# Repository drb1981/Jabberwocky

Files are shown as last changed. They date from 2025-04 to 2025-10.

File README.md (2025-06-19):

# Jabberwocky

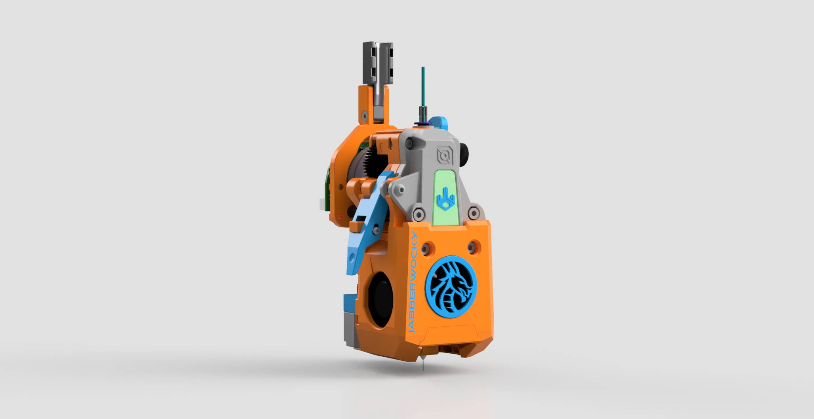
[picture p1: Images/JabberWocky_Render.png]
Jabberwocky Render


**JABBERWOCKY** has been engineered to meet the demanding requirements of filament changing units (FCUs) and multicolor changers. Its extruder is purpose-built to handle the rigorous load and unloading cycles of FCUs, utilizing a Bondtech compound drive gear in an offset configuration, paired with dual LDO non-threaded Orbiter gears for precise and reliable filament control.

The system offers a carefully optimized balance of torque and speed, along with increased surface contact on the filament to ensure stability and consistent feeding throughout operation.

Designed for maximum reliability and serviceability, the toolhead features a tool-free, hinged extruder mechanism, enabling fast and hassle-free maintenance.

Efficient thermal performance is delivered by high-static-pressure fans, ensuring airflow reaches critical areas, while the Phaetus Conch high-flow hotend enables smooth, consistent extrusion at volumes of up to 35 mm³/s.

For complete assembly instructions and additional technical details, please refer to our [Wiki](https://github.com/kinematicdigit/Jabberwocky/wiki).

Kits will be available through LDO Motor's Vendor Channels. Check your favourite vendor for the latest availability.

For support, please visit this [link](https://discord.gg/MPZ4cHm9gm) and visit the Jabberwocky channels. 

---
>**Acknowledgments and Thank You**
>
>*The Jabberwocky project commenced shortly after the release of ERCF V2 in November 2023, directly resulting from my contributions to the ERCF development team. I express my gratitude to my team members, particularly MoggieUK, who has been an exceptional ERCF partner, facilitating the exchange of ideas and addressing challenges related to multi-filament and filament-changing units. The realization of this project was contingent upon the substantial research and development support provided by Jason at LDO Motors. We dedicated numerous months to meticulous material selection, conceptual design, and component identification. Thanks to Dr. Róbert Lőrincz’s for technical assistance and comprehensive responses to my inquiries regarding stepper motors interfacing with ERCF, which also proved highly beneficial for this toolhead, as well as for his pioneering work with the Orbiter gears employed within it. Additionally, Fizzy, another ERCF team member, graciously contributed to the creation of the gorgeous wiki page and documentation, simplifying the user guide for assembling the kit. Finally, I would like to acknowledge the invaluable assistance provided by the many beta testers, who were instrumental in numerous revisions, improvements, and testing conducted during the testing phase.*

>
>*Happy Printing!*
>
>Terrance AKA kinematicdigit
>
Coffee fund donations are always welcome to help support my ongoing efforts. [Click here](https://www.paypal.com/donate/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) to donate. Thank-you!

Shield: [][cc-by-sa]

This work is licensed under a
[Creative Commons Attribution-ShareAlike 4.0 International License][cc-by-sa].

[][cc-by-sa]

[cc-by-sa]: http://creativecommons.org/licenses/by-sa/4.0/
[cc-by-sa-image]: https://licensebuttons.net/l/by-sa/4.0/88x31.png
[cc-by-sa-shield]: https://img.shields.io/badge/License-CC%20BY--SA%204.0-lightgrey.svg

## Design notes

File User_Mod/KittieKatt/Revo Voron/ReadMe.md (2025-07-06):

This Mod will require both the Revo Voron Mount as well as the modified Shroud to work.   The rest of the parts should be the same as normal.  

When printing the Shroud body you will want to use organic supports for the overhangs.

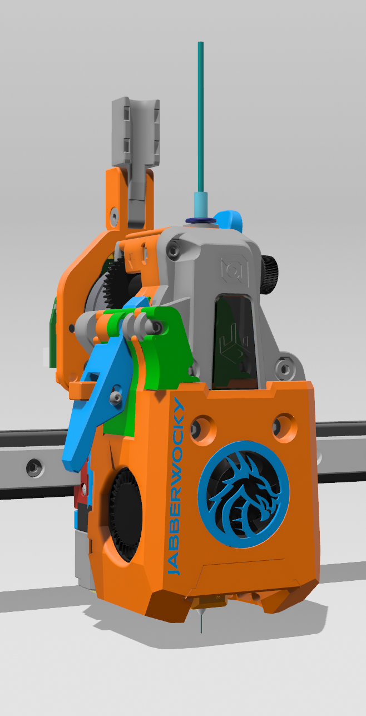
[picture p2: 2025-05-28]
Images/Promo Pic2.png

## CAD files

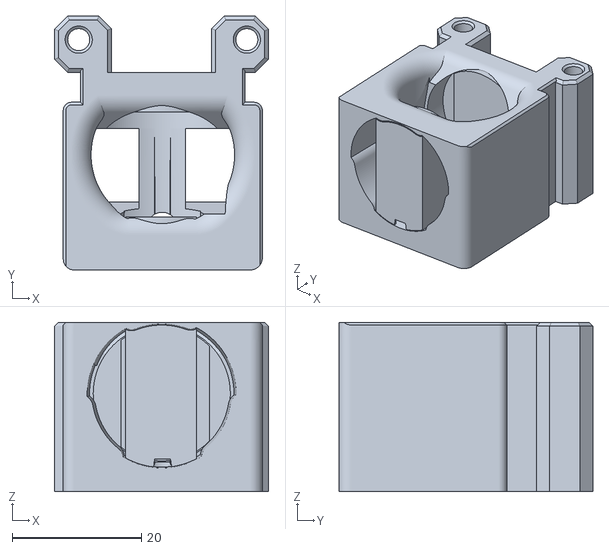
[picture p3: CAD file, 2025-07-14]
Development-testing/shroud_UHF/STL/[b] Rapido_Mount_UHF.stl
33.1 x 39.3 x 26.2

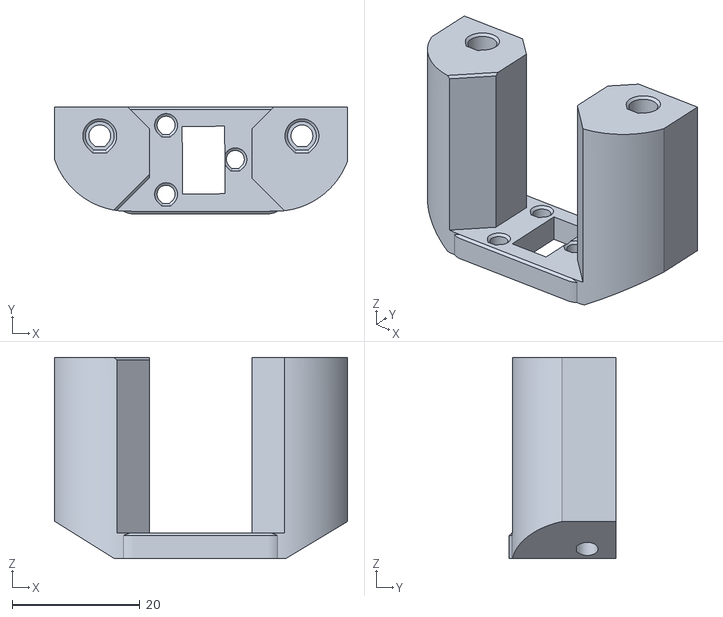
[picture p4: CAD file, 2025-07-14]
Development-testing/shroud_UHF/STL/probe_mounts/Klicky_PCB_Mount_UHF.stl
45.8 x 16.7 x 31.4

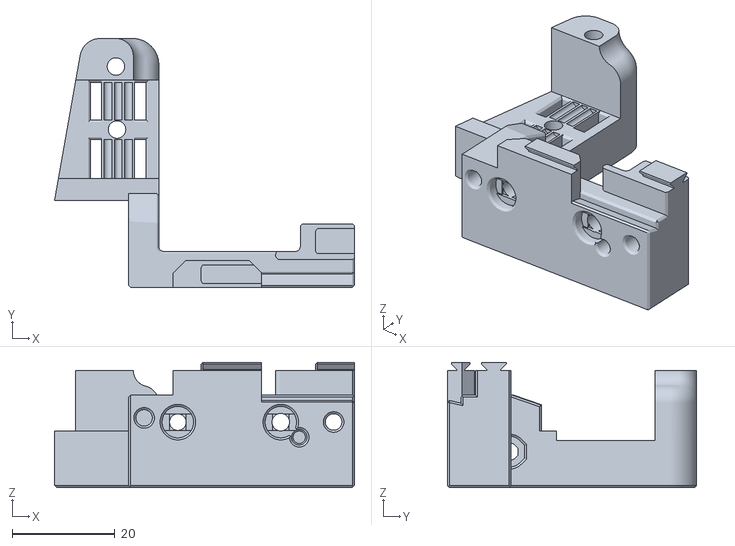
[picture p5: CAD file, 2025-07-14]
Development-testing/Switchwire_Mount/stl/SW_Carriage_Right.stl
58.3 x 48.4 x 24.3

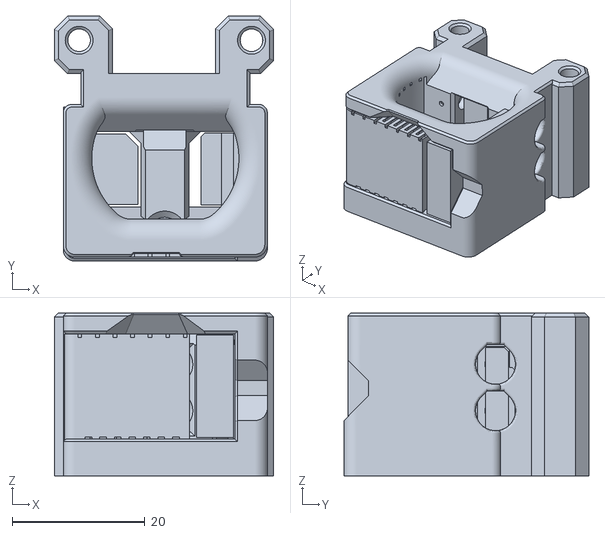
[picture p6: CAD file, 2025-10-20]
Development-testing/V82-RC1/[b] Conch_Mount.stl
33.1 x 37.0 x 24.5

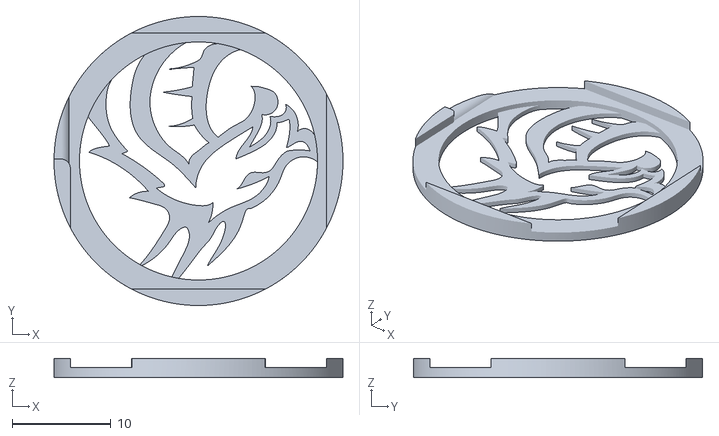
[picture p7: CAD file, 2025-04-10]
Shroud/[2C] Fan Grill.stl
29.2 x 29.2 x 1.92

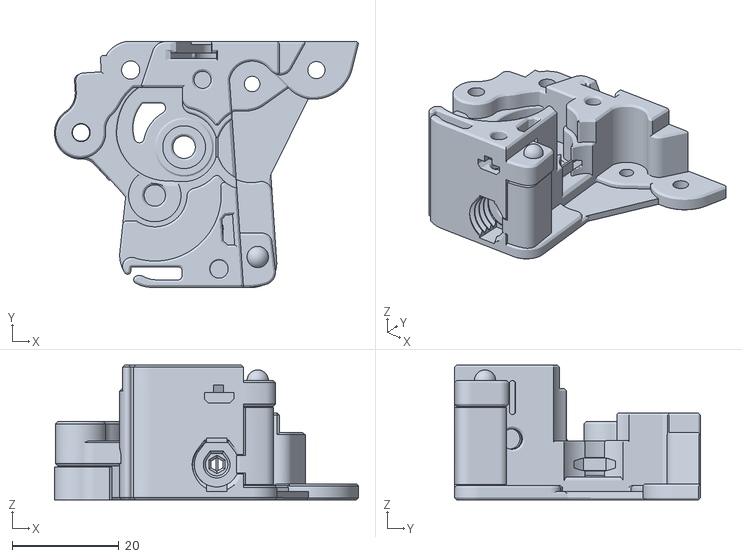
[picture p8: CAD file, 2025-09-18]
STLs/1. Extruder/Mid_Body_M10.stl
56.9 x 46.0 x 25.2

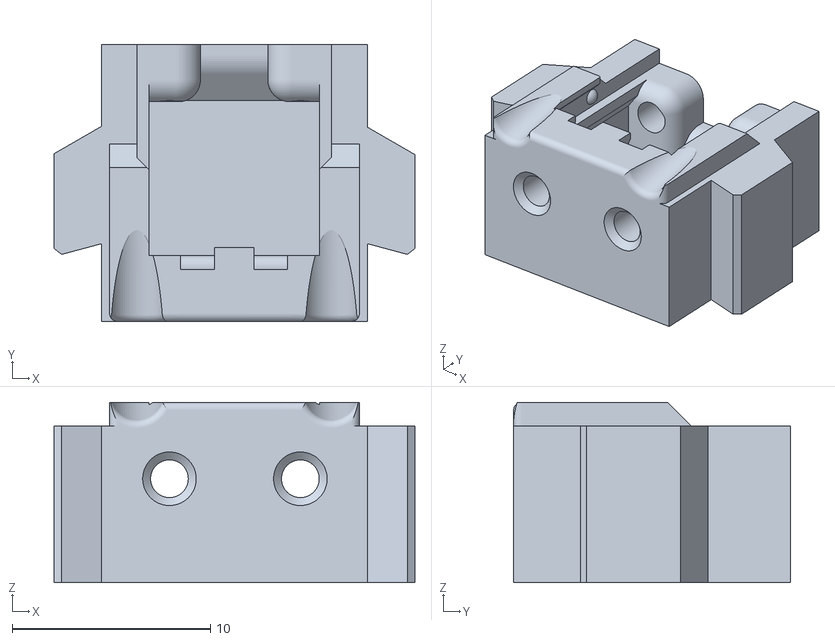
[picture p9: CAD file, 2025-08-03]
STLs/2. Extruder Front Cover/Front_Body_Emount.stl
18.2 x 14.0 x 9.10

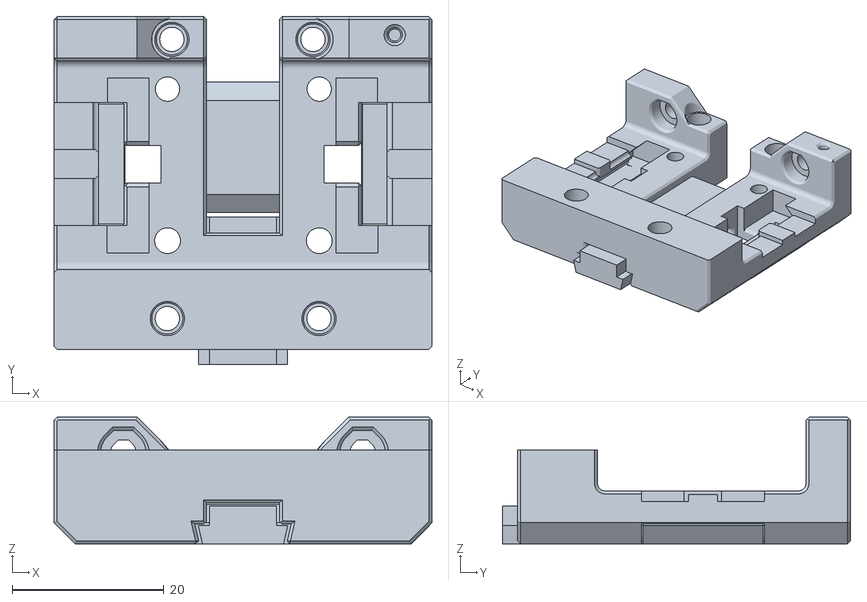
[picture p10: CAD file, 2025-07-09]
STLs/4. Voron 24 - Trident Mounting/experimental-clamp-mount/MGNH12H-Mount_Block_Back.stl
49.8 x 45.9 x 16.7

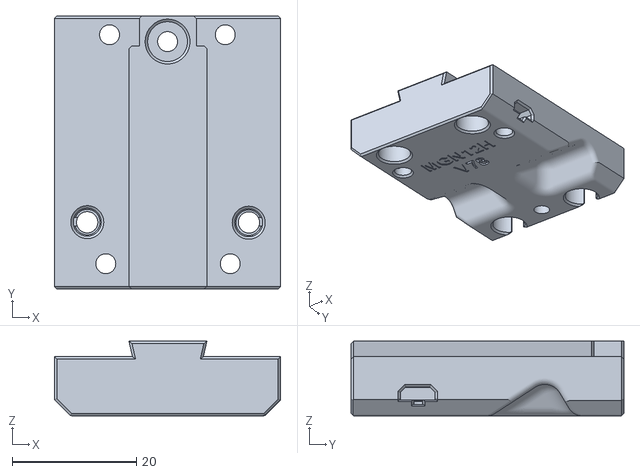
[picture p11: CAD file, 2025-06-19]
STLs/4. Voron 24 - Trident Mounting/traditional_mount/MGN12H_X-Mount_Block_Front.stl
36.4 x 43.9 x 12.0

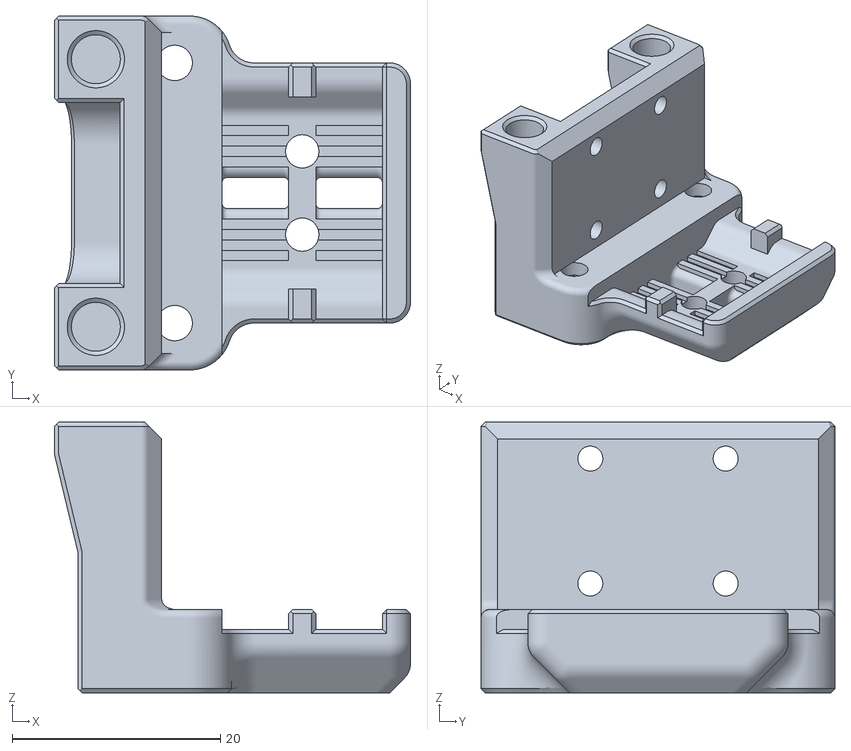
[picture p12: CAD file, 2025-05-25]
STLs/Mount/hartk_mgn7h_bowden_pcb_x_carriage.stl
34.2 x 34.0 x 26.0

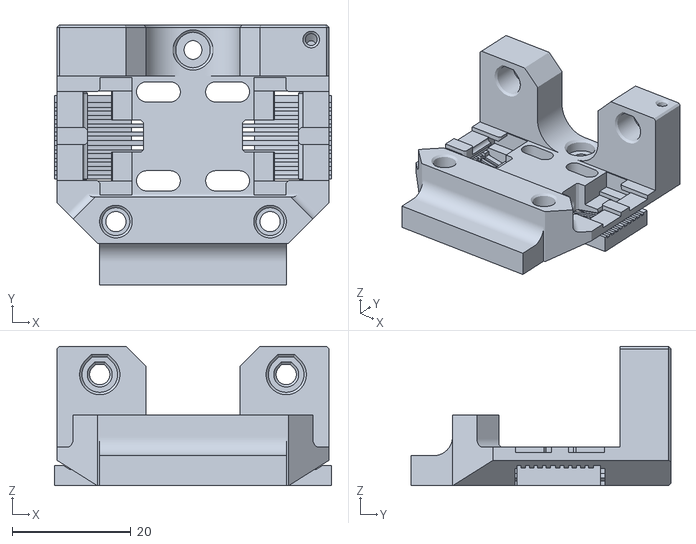
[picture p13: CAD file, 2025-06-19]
STLs/Mount/Micron/JW-MGN9C-H-Mount.stl
46.7 x 43.9 x 23.5

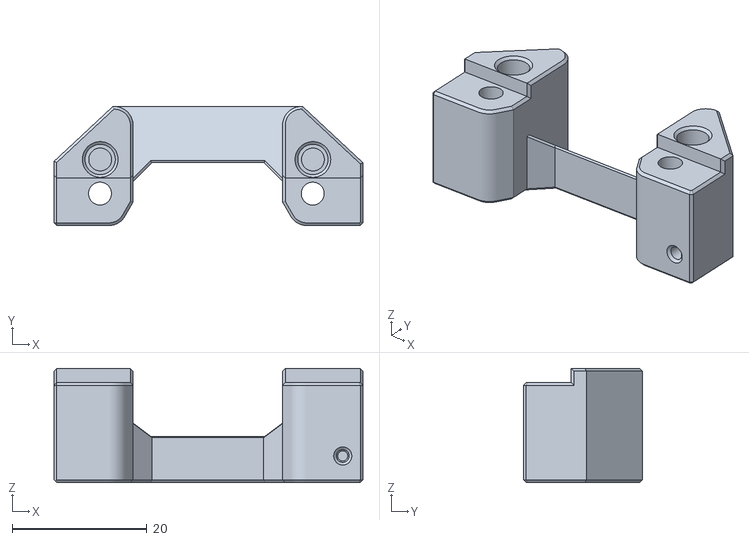
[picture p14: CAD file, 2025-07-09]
STLs/Probes/Carto-beacon/Carto-Beacon_Mount_Adapter.stl
45.9 x 17.7 x 16.9

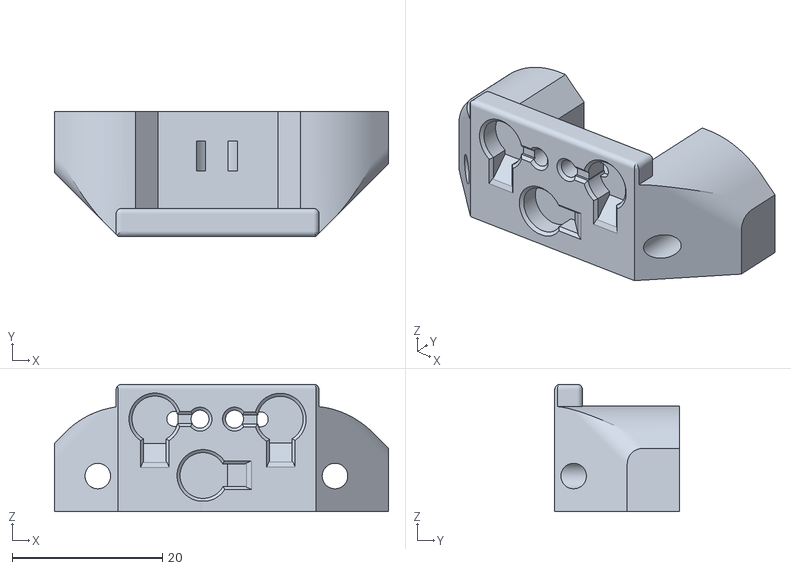
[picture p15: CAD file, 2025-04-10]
STLs/Probes/Klicky/Jabberwocky_Klicky.stl
44.5 x 16.6 x 17.0

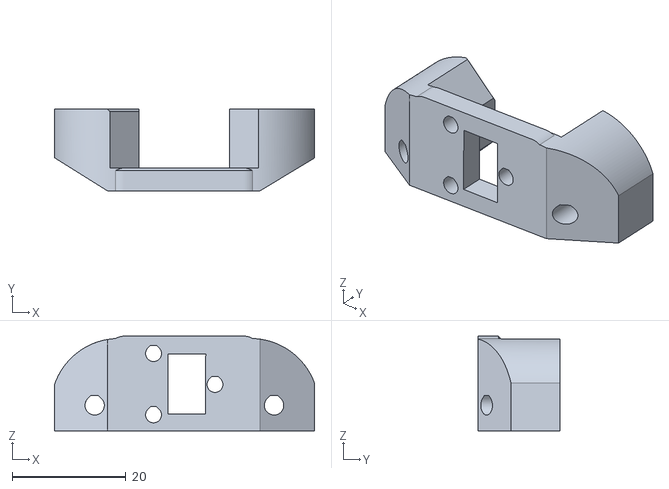
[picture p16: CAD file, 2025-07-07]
STLs/Probes/PCB-Klicky/JW_PCB_klicky_mount_adapter.stl
45.8 x 14.4 x 16.7

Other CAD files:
STLs/Mount/Switchwire/SW_Carriage_Right.stl
STLs/Tools/Carrot_Puller_Case.stl
User_Mod/BO_Andy/Ramalama_Adapter.stl
User_Mod/FizzysTech/HEC_Mount_Cronch_V75.stl
Development-testing/Switchwire_Mount/stl/Belt_clip_x2.stl
Development-testing/Switchwire_Mount/stl/Front_Mount_Plate.stl
Development-testing/Switchwire_Mount/stl/SW_Carriage_Left.stl
Development-testing/V82-RC1/GuiIdler_V82.stl
Development-testing/V82-RC1/LED_Carrier_LDO.stl
Development-testing/V82-RC1/Mid-Body-Base.stl
Development-testing/V82-RC1/NH36_Mounting_Bracket_strain_relief_offset.stl
Development-testing/V82-RC1/[a] Motor_Mount.stl
Development-testing/V82-RC1/[ab] Blade_Holder_LDO_37.stl
Development-testing/shroud_UHF/STL/Fan_Grill_UHF.stl
Development-testing/shroud_UHF/STL/Jabberwocky_Klicky_UHF.stl
Development-testing/shroud_UHF/STL/probe_mounts/Cartographer Mount_UHF.stl
STLs/1. Extruder/Mid_Body_ECAS.stl
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

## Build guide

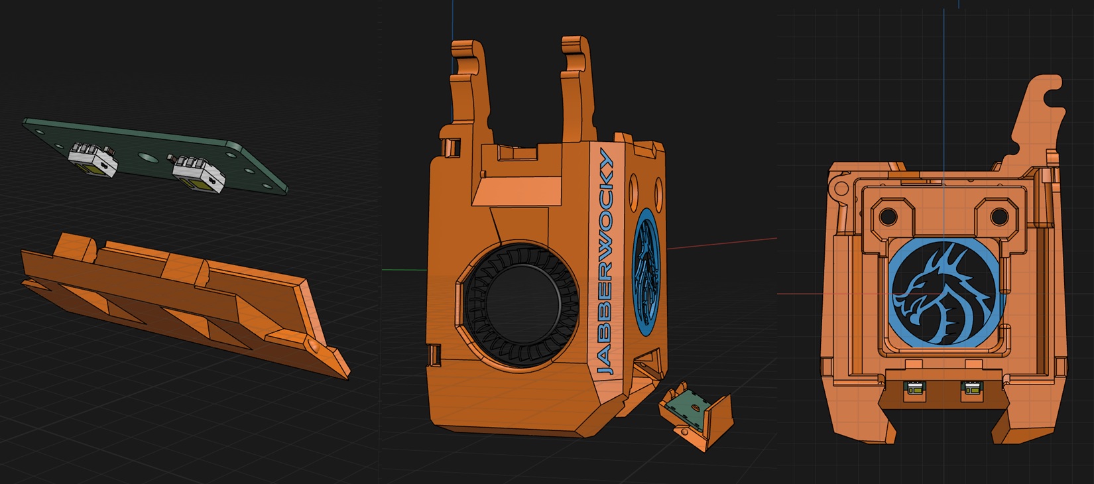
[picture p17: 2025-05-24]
Images/Lower Toolhead Assembly/Installation of hotend LEDs.jpg

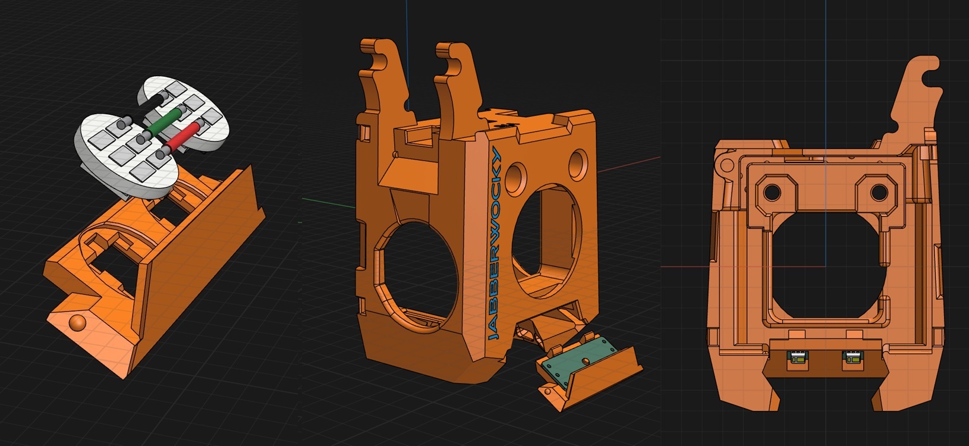
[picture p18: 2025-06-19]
Images/Lower Toolhead Assembly/Installation of hotend Neopixel LEDs.jpg

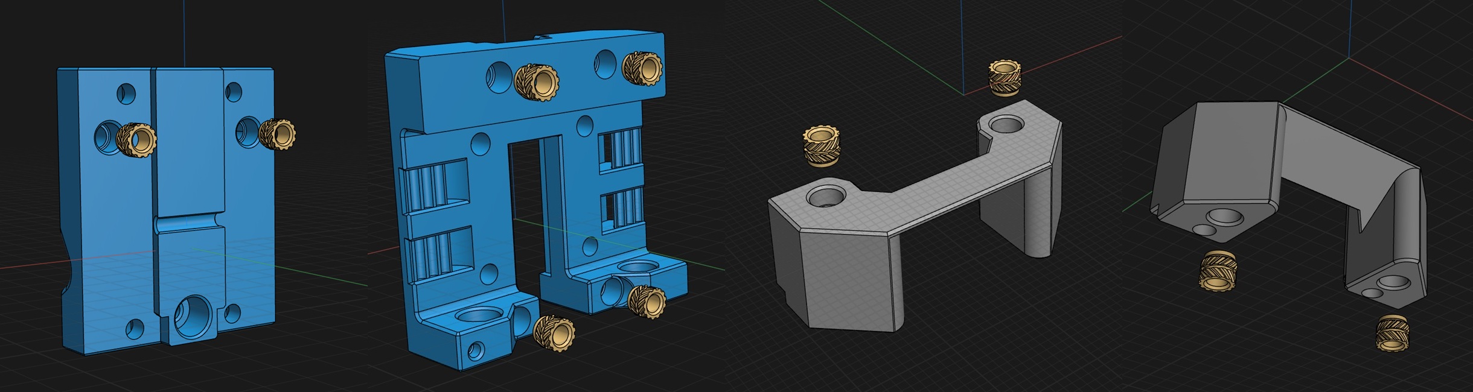
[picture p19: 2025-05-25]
Images/Voron 24 - Trident mounting/Installation of heat inserts.jpg

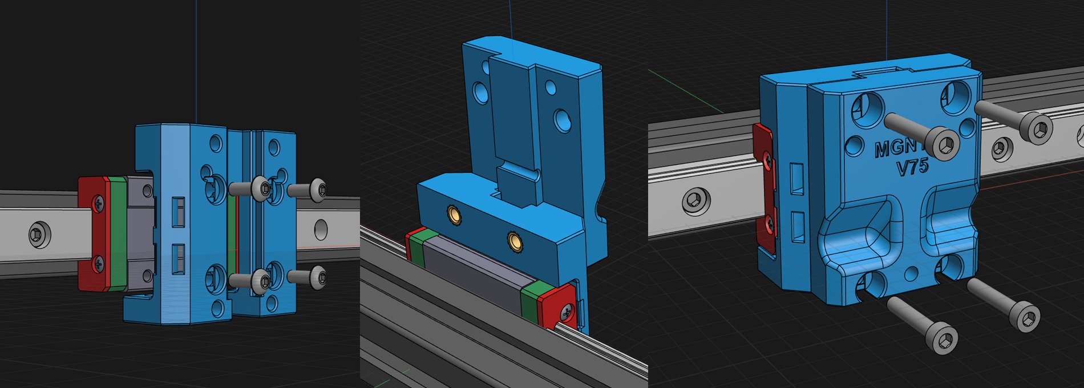
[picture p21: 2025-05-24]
Images/Voron 24 - Trident mounting/Installation of toolhead mount.jpg

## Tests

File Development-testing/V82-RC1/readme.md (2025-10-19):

These are beta test files for Revision V82. 

Please report any feedback to the official Discord channel.

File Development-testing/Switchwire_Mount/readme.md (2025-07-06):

Files pulled temporarily. 

Made an error with alignment

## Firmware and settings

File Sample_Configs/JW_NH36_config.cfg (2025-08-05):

#####################################################################
#   Extruder
#####################################################################
[extruder]
step_pin: nhk:gpio23
dir_pin: !nhk:gpio24
enable_pin: !nhk:gpio25
microsteps: 16
rotation_distance: 35.2												#Be sure to calibrate
gear_ratio: 44:8, 25:17
nozzle_diameter: 0.400
filament_diameter: 1.750
heater_pin: nhk:gpio9
sensor_type: Generic 3950
sensor_pin: nhk:gpio29
pullup_resistor: 2200
#control: pid                                                        # Do PID calibration after initial checks
#pid_Kp: 28.182
#pid_Ki: 1.978
#pid_Kd: 100.397
min_temp: 0
max_temp: 315
min_extrude_temp: 170
max_extrude_only_distance: 1000                                     
max_extrude_cross_section: 30                                       
pressure_advance: 0.052                                             #Be sure to calibrate
pressure_advance_smooth_time: 0.040

[tmc2209 extruder]
sense_resistor: 0.100
uart_pin: nhk:gpio0
tx_pin: nhk:gpio1
interpolate: false
run_current: 0.45                        #.45 minimum offers 12N of force. DO NOT EXCEED .55A as it will cause excess heat.

#####################################################################
#   Fans
#####################################################################
## PCF
[fan]
pin: nhk:gpio6
kick_start_time: .3
off_below: 0.1


## HEF
[heater_fan hotend_fan]
pin: nhk:gpio5
tachometer_pin: nhk:gpio16
tachometer_ppr: 2
max_power: 1.0
kick_start_time: .1
heater: extruder
heater_temp: 50.0
fan_speed: .6

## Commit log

2025-04-10 Initial Push
    [Bearing_Installer.stl, Bearing_Installer_Cap.stl, Blade_installer.stl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]
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2025-05-24 HartK Parts for Voron 0
    [NH36_Board_Cover.step, NH36_Mount_v0.stl, hartk_mgn7h_bowden_pcb_x_carriage.stl]
2025-05-25 Shroud and Grill updates V76
    [MICRON_Fan Grill.stl.stl, [2C] Fan Grill.stl, [a] Fan Grill.stl]
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2025-05-28 Update [a] Fan Grill.stl
    [[a] Fan Grill.stl]
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2025-05-28 Updated STL
    [JW_MGN12H_X-Mount_block_front.stl]
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2025-05-30 Added zip for all files
    [Dual_Neo_Holder.stl, M4_Shim.stl, [ab] blade_holder.stl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]
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2025-05-30 fixed typo
    [JW_config.txt]
2025-05-31 Create JW_MGN12H_X-Mount_block_rear.stl
    Support Part Correction.
    [JW_MGN12H_X-Mount_block_rear.stl]
2025-05-31 MGN12H Block support corrected
    [JW_MGN12H_X-Mount_block_rear.stl]
2025-06-01 CAD and STL updates
    [Bearing_Installer.stl, Bearing_Installer_Cap.stl, Blade_installer.stl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]
2025-06-07 Update LED_Carrier_LDO.stl
    Small update for better fit of PCB LED Carrier
    [LED_Carrier_LDO.stl]
2025-06-07 added Micron STL pack
    [MGN12H_X-Mount_Block_Front.stl, MGN12H_X-Mount_Block_Rear.stl]
2025-06-07 Update [b] Conch_Mount.stl
    V76 update to the Conch Mount. Through two M2.5x8mm SCHS, the Conch hotend is easier to install and secured. This will be the standard way to install, but the old geometry has been left for those tha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
    [[b] Conch_Mount.stl]
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2025-06-11 New Clamp Mounts
    Clamp Mounts for MGN12H and 9H.
    [JW-MGN9C-H-Clamp_x2.stl, JW-MGN9C-H-Mount.stl, JW-MGN9C-H-X-Mount.stl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]
2025-06-13 Minor Update
    Added emergency channel if extruder is installed incorrectly and flange bearing was forgotten. Makes the bearing easily replaceable without full dismantle.
    [[a] Motor_Mount.stl]
2025-06-14 fixed MGN12H_Mount_Front
    [MGN12H_Mount_Block_Front.stl, MGN12H_X-Mount_Block_Front.stl]
2025-06-14 removed MGN12 mount for update
    [MGN12H-Clamp_x2.stl, MGN12H_Mount_Block_Front.stl, MGN12H_X-Mount_Block_Rear.stl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]
2025-06-14 Adjustments made to the Mount Block Front
    [MGN12H-Mount_Block_Back_no_nuts.stl, MGN12H-Mount_Clamp_x2.stl, MGN12H_Mount_Block_Front.stl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]
2025-06-15 Mount for MGN12H
    Adjustments made to screw lengths to two piece mount. Uses T-Nuts instead of Heatsets.
    [MGN12H_X-Mount_Block_Front.stl]
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2025-06-27 Add Kittie Mods
    Added Revo Voron Mount and Shroud files.
    [Jabberwocky_Revo_Voron_Mount.3mf, Jabberwocky_Shroud_Revo_Voron.3mf]
2025-06-29 Update [a] Motor_Mount.stl
    The adjustment motor mount hole has been reduced to prevent the chances of the gears losing mesh.
    It is recommended to replace this part so your motor does not cause damage to the gears should it slip from position.
    [[a] Motor_Mount.stl]
2025-06-29 Small updates and improvements
    - Easier to remove and stronger guidler (does not need the entire extruder to be dismantled to remove guidler-easier to clean and service gear).
    - Mid body now has small bumps to hold the sensor bearings for install (good for one time/first time install)
    - PTFE Tool for cutting tubes to correct length.
    Older guidler is still kept for those that don't want a removable arm.
    [Mid_Body_ECAS.stl, PTFE Tool 14.8mm.stl, [ab] Guidler.stl]
2025-06-30 Update NH36_Mounting_Bracket.stl
    Tolerance adjustment on screwholes.
    [NH36_Mounting_Bracket.stl]
2025-07-05 Switchwire Mount
    Beta version of switchwire mount. Test and report any issues back to discord.
    [Belt_clip_x2.stl, Front_mount_plate.stl, SW_Carriage_Left.stl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]
2025-07-06 updated multi colour parts
    [MGN12H-Clamp_x2.stl, Mount_Block_Back.stl, Mount_Block_Front.stl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]
2025-07-07 Update JW_PCB_klicky_mount_adapter.stl
    Incorrect distance for proper clearance. Adjusted 2.2mm
    [JW_PCB_klicky_mount_adapter.stl]
2025-07-07 Updatged MC with supports
    [Belt_Clip_Left.stl, Belt_Clip_Right.stl, Cartographer Mount.stl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]
2025-07-07 Create washer_pre_V78.stl
    A temporary washer for pre-V78 motor mounting blocks. Print and install into the void to prevent the off chance of the gears loosing mesh. This is a temporary solution for those that have not printed the latest motor mount block (V78).
    [washer_pre_V78.stl]
2025-07-09 Adding Experimental MGN12H Clamp styled mount
    Experimental MGN12H Clam mount. Requires (2) M2x10mm SHCS and (2) M2 Nuts on top of standard kit screws.
    [Carto-Beacon_Mount_Adapter.stl, MGN12H-Mount_Block_Back_no_nuts.stl, MGN12H-Mount_Clamp_x2.stl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]
2025-07-14 Switchwire Mount and UHF Shroud Development Releases
    [Belt_clip_x2.stl, Cartographer Mount_UHF.stl, Fan_Grill_UHF.stl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]
2025-07-16 Update [a] Motor_Mount.stl
    V79 of Motor Mount now with print supports to print flat. This increases the strength of the motor mount across the sheering forces from the tension of the filament.
    [[a] Motor_Mount.stl]
2025-07-18 Update Mid_Body_ECAS.stl
    Small update
    [Mid_Body_ECAS.stl]
2025-07-31 Add files via upload
    Modified from Andy's BFI adapter, this is made to work with they symmetrical BFIs for the Voron 2.4 and Trident.
    [BFI Symetrical Adapter.stl]
2025-08-03 New experimental Screwpost belt clamps
    [MGN12H_6mm_Mount_Block.stl, MGN12H_9mm_Mount_Block.stl, MGN9H_Mount.stl]
2025-08-05 Update and rename JW_config.txt to JW_NH36_config.cfg
    [JW_NH36_config.cfg]
2025-08-12 V80 Updates
    **Jabberwocky V80 UPDATE**
    The motor mount and the mid body of the extruder has some new geometries introduce to make installation easier. This now excludes the need for the M5 spacers that were previously part of the bearing stack for the drive idler gear. This will make installation much easier and ensure alignment of the drive gears. Both parts now have plastic standoffs built into the parts and will no longer accept the M5 spacers in them. A new bearing installation too has also be updated for the bearing installation.
    Prior to this, it was identified that in a small sample of cases some tolerance issues may introduce misalignments as well as the spacers installed incorrect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
    [Bearing_Installer.stl, Mid_Body_ECAS.stl, [a] Motor_Mount.stl]
2025-08-25 Create HEC_Mount_Conch_V80.stl
    Beta version of Conch mount V80
    [HEC_Mount_Conch_V80.stl]
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2025-08-27 V80 Conch Mount
    New Routing for Conch and removing legacy mount point.
    [[b] Conch_Mount.stl]
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2025-08-27 Added M10/P10 coupler version of midbody
    [Mid_Body_ECAS.stl, Mid_Body_M10.stl]
2025-08-30 Conch Mount - M2.5 Counterbore depth adjustment
    Thanks to Kirras._, NerdGriffin, and Justin54321 for identifying the issue.
    Replace previous hotmount with this one.
    [[b] Conch_Mount.stl]
2025-09-02 Wiki update - Extruder Assembly
    [HEC_Mount_Cronch_V75.stl, LDO-DualRGBW_Holder.stl, NH36_Mount_V67.stl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]
2025-09-02 Wiki update - Extruder Front Cover
    [Belt_Clip_Right.stl, SW_Carriage_Left.stl, SW_Carriage_Right.stl]
2025-09-03 Conch V81
    Combines V79 and V80 for legacy compatibility for Batch 1 owners to benefit from the new wiring channel.
    [[b] Conch_Mount.stl, [b] Conch_Mount_batch_1_kits.stl]
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2025-09-09 Reorganized, and depreciated mount options
    reorganized mounts so it's clearer. Two options for mounts which is the traditional one or the screw post version. Screw post version is the recommended one for 9mm belts as it can handle much higher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
    [JW-MGN9C-H-X-Mount.stl, JW_MGN9C_X-Mount.stl, MGN12H_6mm_Mount_Block.stl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]
2025-09-10 Carrot Puller
    A low-fi calibration tool for measuring excessive résistance in a filament path.
    [Carrot_Puller_Case.stl, Carrot_Puller_Gauge.stl]
2025-09-18 V81 update
    Small print geometry corrections made to the Mid-body and Motor Mount.
    [Mid_Body_ECAS.stl, Mid_Body_M10.stl, [a] Motor_Mount.stl]
2025-10-19 Beta Test files for V82 revision
    [Mid-Body-Base.stl, NH36_Mounting_Bracket_strain_relief_offset.stl, [a] Motor_Mount.stl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]
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2025-10-19 Beta V82 - Adding M10 midbody and Guidler
    [GuiIdler_V82.stl]
2025-10-20 Improved Printability on Conch V82
    [HEC_Mount_Conch_V80.stl, [b] Conch_Mount.stl]
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2025-10-30 Add files via upload
    Hex fan shroud, fan grill, and LED diffuser
    [Hex Fan Grill.3mf, Hex Shroud Body.3mf, Hex_Diffuser.3mf]

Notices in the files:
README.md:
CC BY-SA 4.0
